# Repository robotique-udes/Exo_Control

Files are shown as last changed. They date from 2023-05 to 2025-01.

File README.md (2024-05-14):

# Exo_Control

## Table of Contents

- [Exo\_Control](#exo_control)
  - [Table of Contents](#table-of-contents)
  - [Description](#description)
  - [Hardware](#hardware)
  - [Getting Started](#getting-started)
  - [Class description](#class-description)
  - [Testing](#testing)
  - [License](#license)
  - [Acknowledgments](#acknowledgments)
  - [Authors](#authors)

## Description

**BioGénius** is a technical project within the Robotique UdeS group that focuses on designing a lightweight and powerful exoskeleton system. This innovative system provides support to the legs, hips, and back, making walking and load handling easier. Notably, our prototype led the team to secure the first-place position at the Applied Collegiate Exoskeleton (ACE) Competition in the United States in both 2022 and 2023.

Founded in the fall of 2019 by two bioengineering enthusiasts, BioGénius has grown into a team of over fifteen members, bringing together expertise from various engineering disciplines and cohorts. This project represents a pioneering endeavor at the undergraduate engineering level in Quebec.

## Hardware

Our system comprises the following key hardware components:

- **Touch Screen (HMI)**: NX3224F024_11
- **Microcontroller**: ESP32
- **Inertial Measurement Units**: BNO085
- **Motor Drives**: DBH-15
- **Motor**: Servocity 638326

## Getting Started

Getting started with our project is a straightforward process. Simply clone the repository.

## Class description

- main: 
  - Not a class but some things are good to keep in mind:
  - The main is separated in 3 blocs: test, logic and printing
    - Test blocs need to be filled with unit tests for every component, will be commented when not in the process of testing 
    - Logic bloc controls normal operation for the exo, needs to be active when using
    - Printing bloc is for debugging, keep commented otherwise
  - Setup starts IMUs and their wifi functions, comment either of those lines if not needed when testing
- motorControl:
  - This class orchestrates most of the operation in the exo and use the info it receive from various sensors to calculate the needed current for the motors
  - Most of the class is either mathematics or fetching info from other classes
  - Most other classes are called by this one
- imu:
  - BNO055 logic class, used to fetch information from our IMUs, converting it to angles, and sending it to motorControl
  - We use mainly the adafruit bno055 library here
- multiplex:
  - multiplexer control class composed of simple functions used to switch multiplexer chanels
- bnoMultiplex:
  - Bridge between the imu and multiplex classes
  - Used to associate any IMUs to an ID from it's constructor and switch multiplexer channel automatically when using IMU's basic functions
- sonar:
  - Sonar logic class, used to read distance from ground and determine whether or not the foot of the user is grounded
- relay:
  - Relay logic class,  used to turn ON/OFF any relay
- touchScreen:
  - Used to customise the interface and functions of the HMI
- test:
  - Testing class composed of units test for every component
  
## Testing

To ensure the robustness of our system, you can run unit tests on all components by using the Test class.

## License

This project is open source, and you can access the full text of the license [here](link-to-license).

## Acknowledgments

We invite you to explore the [Robotique UdeS website](https://robotiqueudes.ca/) to learn more about our team and discover other intriguing projects we're involved in.

## Authors

The masterminds behind the Exo_Control project are:

- Édouard Moffet, robot 67
- Dannick Bilodeau,  info 68
- Simon Trudeau,  info 68
- Jorand Gagnon,  elec 69

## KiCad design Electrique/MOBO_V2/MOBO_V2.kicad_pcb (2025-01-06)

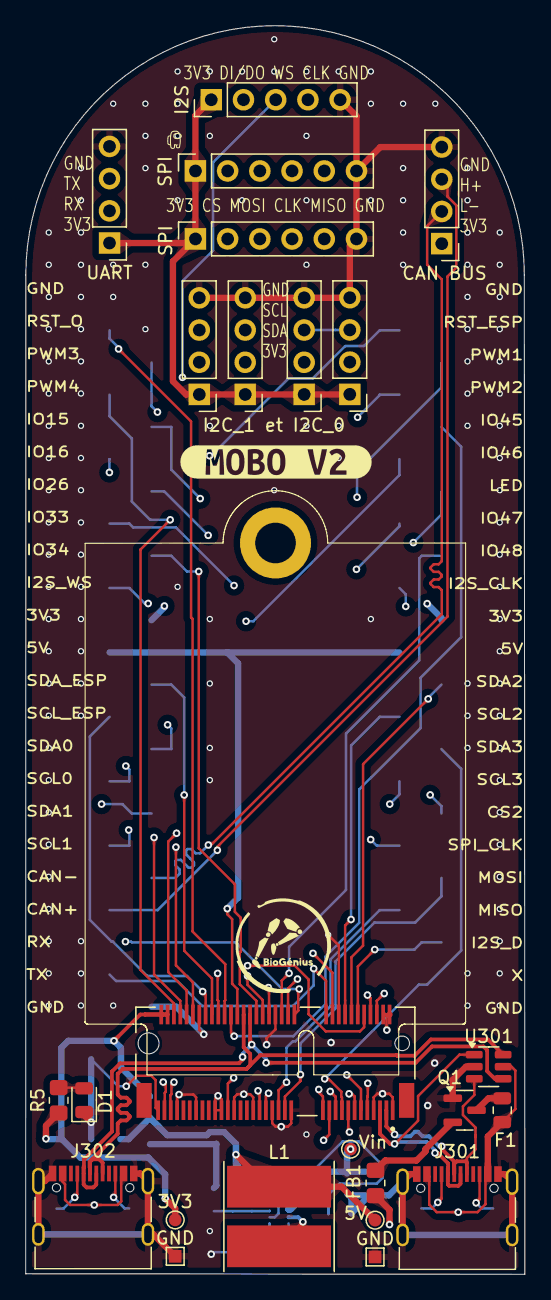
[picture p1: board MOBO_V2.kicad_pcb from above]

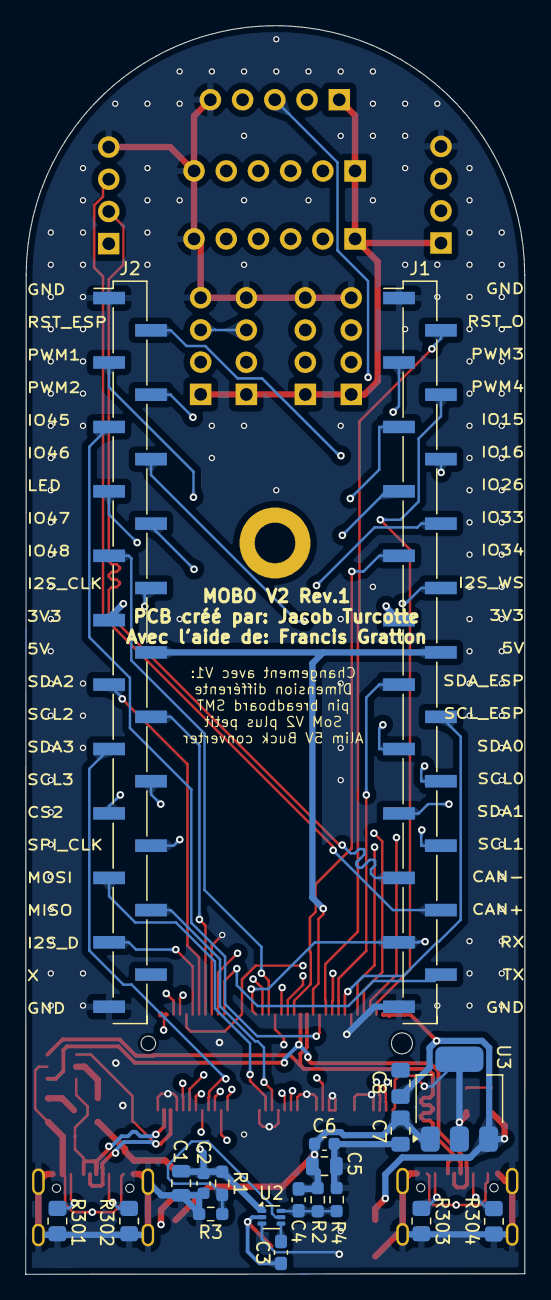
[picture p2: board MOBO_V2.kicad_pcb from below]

Board: 4 copper layers, 39.4 x 98.5 mm, 45 parts (20 on the bottom side), 58 nets.

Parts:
3V3: TP_3v3; TestPoint_Pad_D1.0mm
5V: TP_5V; TestPoint_Pad_D1.0mm
C1: 10µF; C_0805_2012Metric
C2, C6: 0,1µF; C_0603_1608Metric
C3: 0,1µF; C_0603_1608Metric_Pad1.08x0.95mm_HandSolder
C4: 33pF; C_0603_1608Metric_Pad1.08x0.95mm_HandSolder
C5: 22µF; C_0805_2012Metric
C7, C8: 4,7µF; C_0805_2012Metric_Pad1.18x1.45mm_HandSolder
CAN BUS: CAN_BUS; PinHeader_1x04_P2.54mm_Vertical
D1: Green_power; D_0805_2012Metric
F1: SMD0805B110TF; Fuse_0805_2012Metric
FB1: 600 @ 100MHz; R_0805_2012Metric_Pad1.20x1.40mm_HandSolder
GND: TP_GND; TestPoint_Pad_1.0x1.0mm
GND#2: TP_GND_IN; TestPoint_Pad_1.0x1.0mm
I2S: I2S; PinHeader_1x05_P2.54mm_Vertical
J1: Gauche; PinHeader_1x23_P2.54mm_Vertical_SMD_Pin1Left
J2: Droite; PinHeader_1x23_P2.54mm_Vertical_SMD_Pin1Left
J301: USB_C_UART; USB_C_Receptacle_G-Switch_GT-USB-7010ASV
J302: USB_C_DEBUG; USB_C_Receptacle_G-Switch_GT-USB-7010ASV
J307: I2C_0_0; PinHeader_1x04_P2.54mm_Vertical
J308: I2C_0_1; PinHeader_1x04_P2.54mm_Vertical
J309: I2C_1_0; PinHeader_1x04_P2.54mm_Vertical
J310: I2C_1_1; PinHeader_1x04_P2.54mm_Vertical
L1: 3,3µH 20mOhm; L_TDK_VLP8040
Q1: AO3401A; SOT-23
R1: 100k; R_0603_1608Metric_Pad0.98x0.95mm_HandSolder
R2: 158k; R_0603_1608Metric_Pad0.98x0.95mm_HandSolder
R3: 28k; R_0603_1608Metric_Pad0.98x0.95mm_HandSolder
R4: 30k; R_0603_1608Metric_Pad0.98x0.95mm_HandSolder
R5: 330; R_0805_2012Metric_Pad1.20x1.40mm_HandSolder
R301, R302, R303, R304: 5.1k; R_0805_2012Metric_Pad1.20x1.40mm_HandSolder
SPI: Conn_SPI; PinSocket_1x06_P2.54mm_Vertical
SPI#2: Conn_Module_SD; PinSocket_1x06_P2.54mm_Vertical
U1: AMPHENOL_MDT320E01001
U2: TPS562242DRLR; SOT-563
U3: AP7361C-33E; SOT-223-3_TabPin2
U301: SRV05-4; SOT-23-6
UART: UART; PinHeader_1x04_P2.54mm_Vertical
Vin: TP_VIN; TestPoint_Pad_D1.0mm
kibuzzard-66E82988: G***; kibuzzard-66E82988

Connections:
CAN_N: CAN BUS.2, J1.19, U1.73 (CAN_L_MCP2515)
CAN_P: CAN BUS.3, J1.20, U1.71 (CAN_H_MCP2515)
CHIP_EN: J2.2, U1.56 (RESET_ESP32)
CS_1: SPI#2.2, U1.20 (CS_1)
CS_2: J2.17, SPI.2, U1.21 (CS_2)
DEBUG_D+: J302.A6 (D+), J302.B6 (D+), U1.48 (USB_DEBUG_D+), U301.6 (IO4)
DEBUG_D-: J302.A7 (D-), J302.B7 (D-), U1.46 (USB_DEBUG_D-), U301.4 (IO3)
FT231_D+: J301.A6 (D+), J301.B6 (D+), U1.3 (USB_D+_FT231), U301.3 (IO2)
FT231_D-: J301.A7 (D-), J301.B7 (D-), U1.5 (USB_D-_FT231), U301.1 (IO1)
GND: C1.2, C2.2, C5.2, C6.2, C7.1, C8.1, CAN BUS.4, D1.1 (K), GND.1, GND#2.1, I2S.5, J1.1, J1.23, J2.1, J2.23, J301.A1 (GND), J301.A12 (GND), J301.B1 (GND), J301.B12 (GND), J301.S1 (SHIELD), J302.A1 (GND), J302.A12 (GND), J302.B1 (GND), J302.B12 (GND), J302.S1 (SHIELD), J307.4, J308.4, J309.4, J310.4, Q1.1 (G), R3.2, R4.2, R301.2, R302.2, R303.2, R304.2, SPI.6, SPI#2.6, U1.1 (GND), U1.7 (GND), U1.18 (GND), U1.33 (GND), U1.38 (GND), U1.39 (GND), U1.45 (GND), U1.51 (GND), U1.55 (GND), U1.57 (GND), U1.62 (GND), U1.63 (GND), U1.69 (GND), U1.75 (GND), U2.3 (GND), U3.2 (GND), U301.2 (VN), UART.4
GPIO15: J1.5, U1.40 (GPIO15)
GPIO16: J1.6, U1.41 (GPIO16)
GPIO17_U1_TXD: J1.22, U1.22 (UART_TX), UART.3
GPIO18_U1_RXD: J1.21, U1.32 (UART_RX), UART.2
GPIO26: J1.7, U1.42 (GPIO26)
GPIO33: J1.8, U1.43 (GPIO33)
GPIO34: J1.9, U1.44 (GPIO34)
GPIO38_ADDRESSABLE_LED: J2.7, U1.6 (GPIO38&LED)
GPIO45: J2.5, U1.52 (GPIO45)
GPIO46: J2.6, U1.53 (GPIO46)
GPIO47: J2.8, U1.34 (RST_OTHER)
GPIO48/CAN_INT: J2.9, U1.36 (GPIO48)
I2C_SCL_0_TCA: J1.16, J307.3, J308.3, U1.11 (I2C_SCL_1_TCA)
I2C_SCL_1_TCA: J1.18, J309.3, J310.3, U1.15 (I2C_SCL_2_TCA)
I2C_SCL_2_TCA: J2.14, U1.16 (I2C_SCL_3_TCA)
I2C_SCL_3_TCA: J2.16, U1.19 (I2C_SCL_4_TCA)
I2C_SCL_ESP32: J1.14, U1.60 (I2C_SCL_ESP32)
I2C_SDA_0_TCA: J1.15, J307.2, J308.2, U1.9 (I2C_SDA_1_TCA)
I2C_SDA_1_TCA: J1.17, J309.2, J310.2, U1.13 (I2C_SDA_2_TCA)
I2C_SDA_2_TCA: J2.13, U1.14 (I2C_SDA_3_TCA)
I2C_SDA_3_TCA: J2.15, U1.17 (I2C_SDA_4_TCA)
I2C_SDA_ESP32: J1.13, U1.58 (I2C_SDA_ESP32)
I2S_BCLK: I2S.4, J2.10, U1.8 (I2S_BCLK)
I2S_DIN/DOUT: I2S.2, J2.21, U1.12 (I2S_DIN/DOUT)
I2S_WS: I2S.3, J1.10, U1.10 (I2S_WS)
unnamed: D1.2 (A), R5.2
unnamed: J301.A5 (CC1), R302.1
unnamed: J301.B5 (CC2), R301.1
unnamed: J302.A5 (CC1), R304.1
unnamed: J302.B5 (CC2), R303.1
unnamed: F1.2, Q1.3 (D)
unnamed: FB1.1, Q1.2 (S)
unnamed: R1.2, R3.1, U2.5 (EN)
unnamed: C3.1, L1.1, U2.2 (SW)
unnamed: C3.2, U2.4 (VBST)
unnamed: C4.2, R2.2, R4.1, U2.6 (VFB)
PWM_1: J2.3, U1.64 (PWM_1_PCA)
PWM_2: J2.4, U1.66 (PWM_2_PCA)
PWM_3: J1.3, U1.68 (PWM_3_PCA)
PWM_4: J1.4, U1.70 (PWM_4_PCA)
RESET_OTHERS: J1.2, U1.54 (RESET_AUTRES)
SPI_CLK_ESP32: J2.18, SPI.4, SPI#2.4, U1.23 (SPI_CLK)
SPI_MISO_ESP32: J2.20, SPI.5, SPI#2.5, U1.37 (SPI_MISO)
SPI_MOSI_ESP32: J2.19, SPI.3, SPI#2.3, U1.35 (SPI_MOSI)
VBUS: F1.1, J301.A4 (VBUS), J301.A9 (VBUS), J301.B4 (VBUS), J301.B9 (VBUS), J302.A4 (VBUS), J302.A9 (VBUS), J302.B4 (VBUS), J302.B9 (VBUS), U301.5 (VP)
VIN_PROTECTION: C1.1, C2.1, FB1.2, R1.1, U2.1 (VIN), Vin.1
Vcc_3V3: 3V3.1, C8.2, CAN BUS.1, I2S.1, J1.11, J2.11, J307.1, J308.1, J309.1, J310.1, R5.1, SPI.1, SPI#2.1, U1.2 (Vcc_3v3), U1.4 (Vcc_3v3), U1.72 (Vcc_3v3), U1.74 (Vcc_3v3), U3.3 (VO), UART.1
Vcc_5V: 5V.1, C4.1, C5.1, C6.1, C7.2, J1.12, J2.12, L1.2, R2.1, U1.50 (Vcc_5V), U3.1 (VI)

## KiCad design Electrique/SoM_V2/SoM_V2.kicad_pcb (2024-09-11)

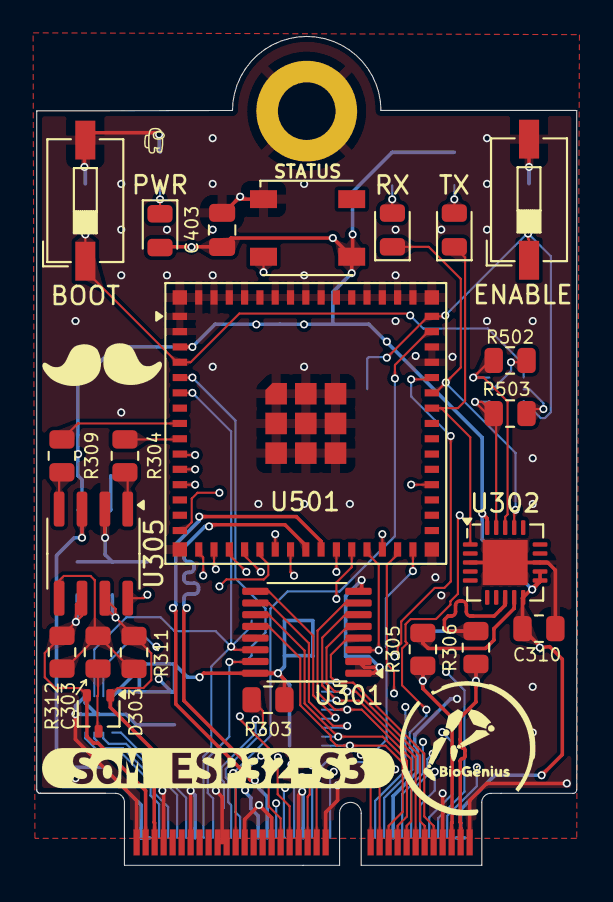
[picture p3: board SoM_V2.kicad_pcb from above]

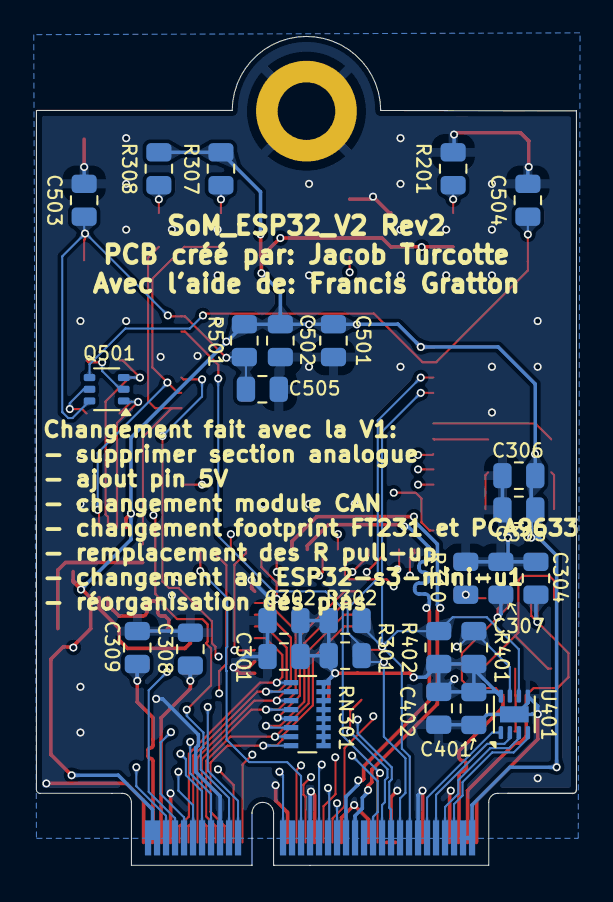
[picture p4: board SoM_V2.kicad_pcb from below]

Board: 4 copper layers, 30.0 x 46.1 mm, 52 parts (27 on the bottom side), 62 nets.

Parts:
BOOT: SW_BOOT; SW_DIP_SPSTx01_Slide_6.7x4.1mm_W6.73mm_P2.54mm_LowProfile_J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
C301, C501: 10µF; R_0805_2012Metric
C302, C304, C306, C307, C310, C502, C504, C505: 0.1µF; R_0805_2012Metric
C303, C305, C401, C503: 1µF; R_0805_2012Metric
C308, C309: 47pF; R_0805_2012Metric
C402: 100nF; R_0805_2012Metric
C403: 100n; C_0805_2012Metric
D303: SP0502BAJT; SOT-323_SC-70
ENABLE: SW_CHIP_EN; SW_DIP_SPSTx01_Slide_6.7x4.1mm_W6.73mm_P2.54mm_LowProfile_J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
PWR: GREEN; LED_0805_2012Metric
Q501: MBT3904DW1T1G; SOT-363_SC-70-6
R201, R307, R308: 330; R_0805_2012Metric
R301, R302, R303, R304, R309, R310, R401, R402: 1k; R_0805_2012Metric
R305, R306: 27; R_0805_2012Metric
R311, R312: 60; R_0805_2012Metric
R501, R502, R503: 10k; R_0805_2012Metric
RN301: R_Pack08_Split; R_Array_Convex_8x0602
RX: TX; LED_0805_2012Metric
STATUS: FZ2812-5050; LED_Inolux_IN-PI554FCH_PLCC4_5.0x5.0mm_P3.2mm
TX: RX; LED_0805_2012Metric
U201: NGFF_E
U301: TCA9546APWR; TSSOP-16_4.4x5mm_P0.65mm
U302: FT231XQ; QFN-20-1EP_4x4mm_P0.5mm_EP2.5x2.5mm
U305: SN65HVD230; SOIC-8_3.9x4.9mm_P1.27mm
U401: PCA9633DP1; DFN-8-1EP_2x2mm_P0.5mm_EP0.9x1.6mm
U501: ESP32-S3-MINI-1U; ESP32-S2-MINI-1U
kibuzzard-66E094ED: G***; kibuzzard-66E094ED

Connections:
/Communication/CAN+: C307.2, D303.1 (K), R311.1, U201.71 (CAN_H_MCP2515), U305.7 (CANH)
/Communication/CAN-: C304.1, D303.2 (K), R312.2, U201.73 (CAN_L_MCP2515), U305.6 (CANL)
/Communication/D+: R306.2, U302.8 (USBDP)
/Communication/D-: R305.2, U302.9 (USBDM)
/Communication/DR+: C309.1, R306.1, U201.3 (USB_D+_FT231)
/Communication/DR-: C308.1, R305.1, U201.5 (USB_D-_FT231)
CHIP_EN: C503.1, C505.1, ENABLE.1, Q501.6 (C1), R501.2, U201.56 (RESET_ESP32), U501.45 (EN)
CS_1: U201.20 (CS_1), U501.15 (IO11)
CS_2: U201.21 (CS_2), U501.25 (IO21)
DEBUG+: U201.48 (USB_DEBUG_D+), U501.24 (IO20)
DEBUG-: U201.46 (USB_DEBUG_D-), U501.23 (IO19)
DTR: Q501.3 (C2), R502.1, U302.18 (~DTR)
GND: BOOT.2, C301.2, C302.2, C304.2, C305.2, C306.2, C307.1, C308.2, C309.2, C310.2, C401.2, C402.2, C403.2, C501.2, C502.2, C503.2, C504.2, C505.2, ENABLE.2, R201.2, R310.1, STATUS.1 (VSS), U201.1 (GND), U201.7 (GND), U201.18 (GND), U201.33 (GND), U201.38 (GND), U201.39 (GND), U201.45 (GND), U201.51 (GND), U201.55 (GND), U201.57 (GND), U201.62 (GND), U201.63 (GND), U201.69 (GND), U201.75 (GND), U301.1 (A0), U301.2 (A1), U301.8 (GND), U301.13 (A2), U302.3 (GND), U302.13 (GND), U302.21 (GND), U305.2 (GND), U401.5 (GND), U501.1 (GND), U501.2 (GND), U501.42 (GND), U501.43 (GND), U501.46 (GND), U501.47 (GND), U501.48 (GND), U501.49 (GND), U501.50 (GND), U501.51 (GND), U501.52 (GND), U501.53 (GND), U501.54 (GND), U501.55 (GND), U501.56 (GND), U501.57 (GND), U501.58 (GND), U501.59 (GND), U501.60 (GND), U501.61 (GND), U501.62 (GND), U501.63 (GND), U501.64 (GND), U501.65 (GND)
GPIO0_BOOT: BOOT.1, C504.1, Q501.4 (E2), U501.4 (IO0)
GPIO4/RXD: R309.1, U501.8 (IO4)
GPIO5/TXD: R304.1, U501.9 (IO5)
GPIO15: U201.40 (GPIO15), U501.19 (IO15)
GPIO16: U201.41 (GPIO16), U501.20 (IO16)
GPIO17_U1_TXD: U201.22 (UART_TX), U501.21 (IO17)
GPIO18_U1_RXD: U201.32 (UART_RX), U501.22 (IO18)
GPIO26: U201.42 (GPIO26), U501.26 (IO26)
GPIO33: U201.43 (GPIO33), U501.28 (IO33)
GPIO34: U201.44 (GPIO34), U501.29 (IO34)
GPIO38_ADDRESSABLE_LED: STATUS.2 (DIN), U201.6 (GPIO38&LED), U501.34 (IO38)
GPIO45: U201.52 (GPIO45), U501.41 (IO45)
GPIO46: U201.53 (GPIO46), U501.44 (IO46)
GPIO48/CAN_INT: U201.36 (GPIO48), U501.30 (IO48)
I2C_SCL_0_TCA: RN301.2 (R2.1), U201.11 (I2C_SCL_1_TCA), U301.5 (SC0)
I2C_SCL_1_TCA: RN301.4 (R4.1), U201.15 (I2C_SCL_2_TCA), U301.7 (SC1)
I2C_SCL_2_TCA: RN301.6 (R6.1), U201.16 (I2C_SCL_3_TCA), U301.10 (SC2)
I2C_SCL_3_TCA: RN301.8 (R8.1), U201.19 (I2C_SCL_4_TCA), U301.12 (SC3)
I2C_SCL_ESP32: R302.2, R402.2, U201.60 (I2C_SCL_ESP32), U301.14 (SCL), U401.6 (SCL6), U501.6 (IO2)
I2C_SDA_0_TCA: RN301.1 (R1.1), U201.9 (I2C_SDA_1_TCA), U301.4 (SD0)
I2C_SDA_1_TCA: RN301.3 (R3.1), U201.13 (I2C_SDA_2_TCA), U301.6 (SD1)
I2C_SDA_2_TCA: RN301.5 (R5.1), U201.14 (I2C_SDA_3_TCA), U301.9 (SD2)
I2C_SDA_3_TCA: RN301.7 (R7.1), U201.17 (I2C_SDA_4_TCA), U301.11 (SD3)
I2C_SDA_ESP32: R301.2, R401.2, U201.58 (I2C_SDA_ESP32), U301.15 (SDA), U401.7 (SDA), U501.5 (IO1)
I2S_BCLK: U201.8 (I2S_BCLK), U501.16 (IO12)
I2S_DIN/DOUT: U201.12 (I2S_DIN/DOUT), U501.18 (IO14)
I2S_WS: U201.10 (I2S_WS), U501.17 (IO13)
unnamed: PWR.2 (A), R201.1
unnamed: R307.1, RX.2 (A)
unnamed: R308.1, TX.2 (A)
unnamed: C303.2, D303.3 (A)
unnamed: Q501.2 (B1), R502.2
unnamed: Q501.5 (B2), R503.2
unnamed: U201.64 (PWM_1_PCA), U401.1 (PWM1)
unnamed: U201.66 (PWM_2_PCA), U401.2 (PWM2)
unnamed: U201.68 (PWM_3_PCA), U401.3 (PWM3)
unnamed: U201.70 (PWM_4_PCA), U401.4 (PWM4)
unnamed: R304.2, U305.1 (D)
unnamed: R309.2, U305.4 (R)
unnamed: R310.2, U305.8 (Rs)
RESET_OTHERS: R303.2, U201.54 (RESET_AUTRES), U301.3 (RESET_N), U501.27 (IO47)
RTS: Q501.1 (E1), R503.1, U302.19 (~RTS)
SPI_CLK_ESP32: U201.23 (SPI_CLK), U501.10 (IO6)
SPI_MISO_ESP32: U201.37 (SPI_MISO), U501.12 (IO8)
SPI_MOSI_ESP32: U201.35 (SPI_MOSI), U501.11 (IO7)
U0RXD: RX.1 (K), U302.17 (TXD), U501.40 (RXD0)
U0TXD: TX.1 (K), U302.1 (RXD), U501.39 (TXD0)
Vcc_3V3: C301.1, C302.1, C305.1, C306.1, C310.1, C401.1, C402.1, C403.1, C501.1, C502.1, PWR.1 (K), R301.1, R302.1, R303.1, R307.2, R308.2, R401.1, R402.1, R501.1, RN301.9 (R8.2), RN301.10 (R7.2), RN301.11 (R6.2), RN301.12 (R5.2), RN301.13 (R4.2), RN301.14 (R3.2), RN301.15 (R2.2), RN301.16 (R1.2), STATUS.3 (VDD), U201.2 (Vcc_3v3), U201.4 (Vcc_3v3), U201.72 (Vcc_3v3), U201.74 (Vcc_3v3), U301.16 (VCC), U302.10 (3V3OUT), U302.11 (~RESET), U302.12 (VCC), U302.20 (VCCIO), U305.3 (VCC), U401.8 (VCC), U501.3 (3V3)
Vref_CAN: C303.1, R311.2, R312.1, U305.5 (Vref)

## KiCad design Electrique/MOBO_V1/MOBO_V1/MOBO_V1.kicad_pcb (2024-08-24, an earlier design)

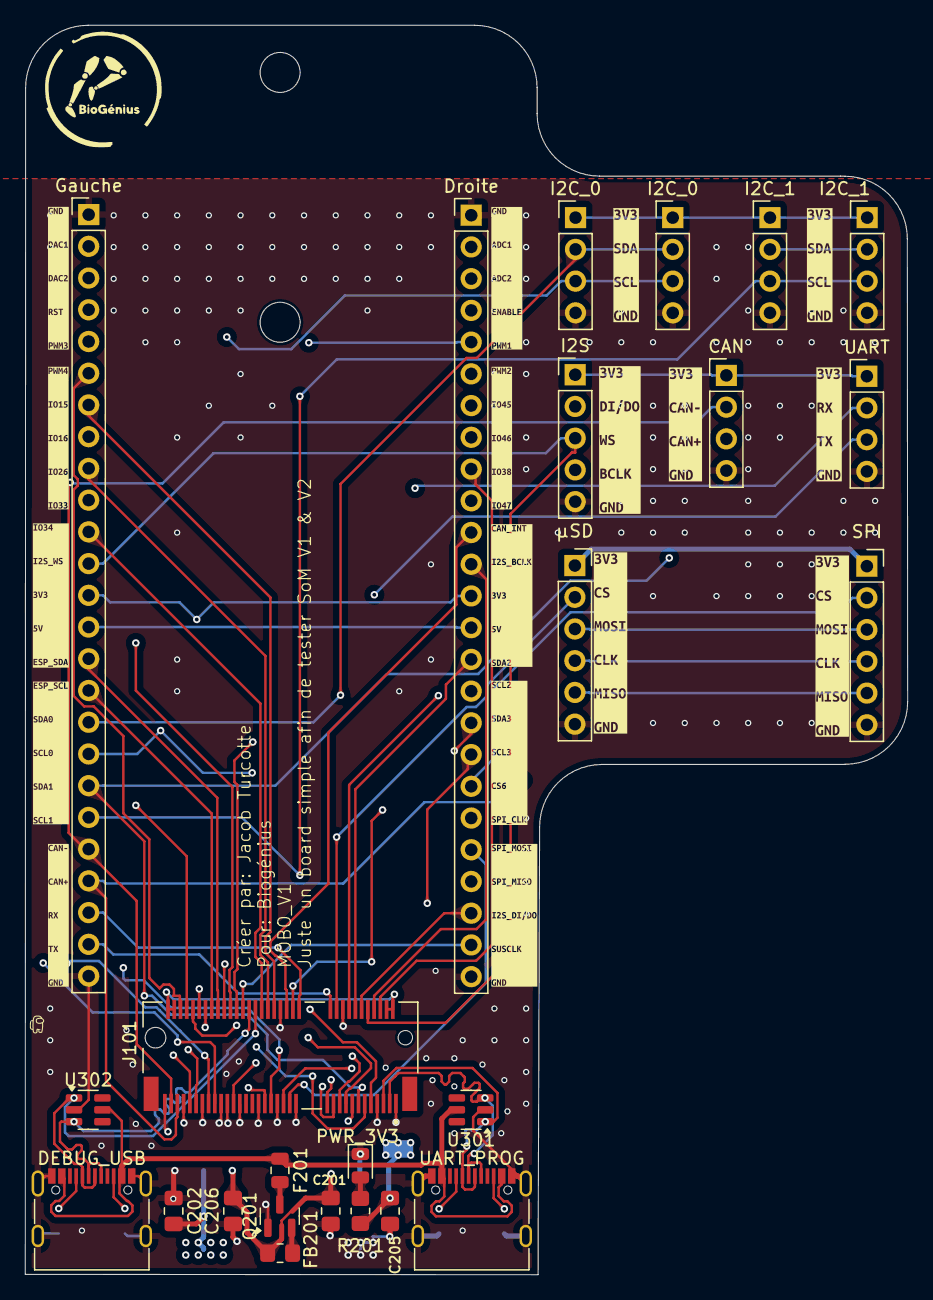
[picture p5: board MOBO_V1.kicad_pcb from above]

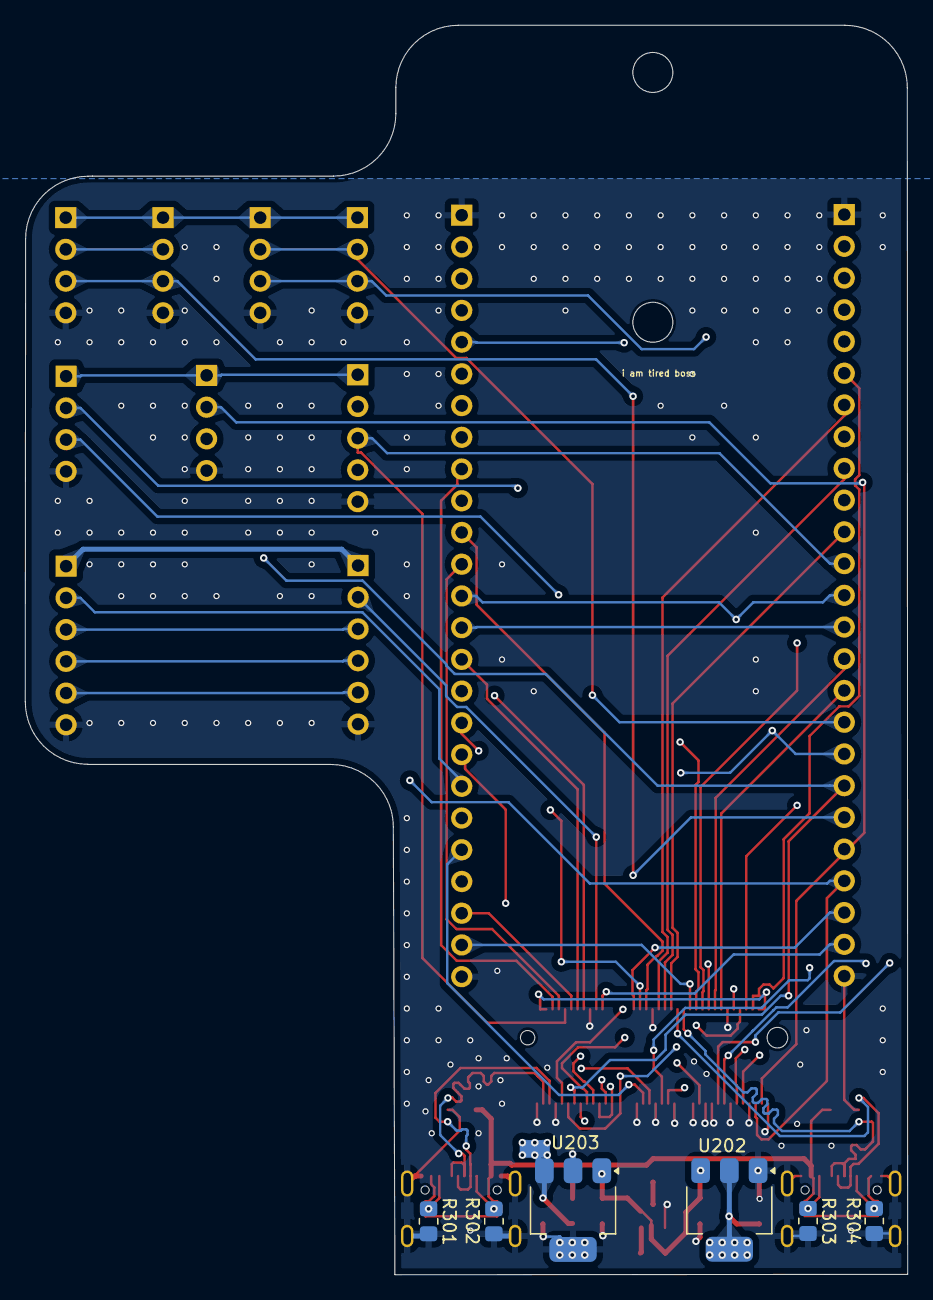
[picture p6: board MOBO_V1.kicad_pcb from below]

Board: 4 copper layers, 70.6 x 100.0 mm, 50 parts (6 on the bottom side), 60 nets.

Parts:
C201: 10uF; C_0805_2012Metric_Pad1.18x1.45mm_HandSolder
C202: 22µF; C_0805_2012Metric_Pad1.18x1.45mm_HandSolder
C205, C206: 4,7µF; C_0805_2012Metric_Pad1.18x1.45mm_HandSolder
CAN: CAN_BUS; PinHeader_1x04_P2.54mm_Vertical
DEBUG_USB: USB_C_DEBUG; USB_C_Receptacle_G-Switch_GT-USB-7010ASV
Droite: Droite; PinHeader_1x25_P2.54mm_Vertical
F201: SMD0805B110TF; Fuse_0805_2012Metric
FB201: 600 @ 100MHz; R_0805_2012Metric_Pad1.20x1.40mm_HandSolder
Gauche: Gauche; PinHeader_1x25_P2.54mm_Vertical
I2C_0: I2C_0_1; PinHeader_1x04_P2.54mm_Vertical
I2C_0#2: I2C_0_0; PinHeader_1x04_P2.54mm_Vertical
I2C_1: I2C_1_0; PinHeader_1x04_P2.54mm_Vertical
I2C_1#2: I2C_1_1; PinHeader_1x04_P2.54mm_Vertical
I2S: I2S; PinHeader_1x05_P2.54mm_Vertical
J101: AMPHENOL_MDT320E01001
PWR_3V3: Green_power; D_0805_2012Metric
Q201: AO3401A; SOT-23
R201: 330; R_0805_2012Metric_Pad1.20x1.40mm_HandSolder
R301, R302, R303, R304: 5.1k; R_0805_2012Metric_Pad1.20x1.40mm_HandSolder
SPI: Conn_SPI; PinSocket_1x06_P2.54mm_Vertical
U202: AMS1117-5.0; SOT-223-3_TabPin2
U203: AP7361C-33E; SOT-223-3_TabPin2
U301, U302: SRV05-4; SOT-23-6
UART: UART; PinHeader_1x04_P2.54mm_Vertical
UART_PROG: USB_C_UART; USB_C_Receptacle_G-Switch_GT-USB-7010ASV
V1_mount, V2_mount: MountingHole_3.2mm_M3
kibuzzard-66C7DEE4, kibuzzard-66C7DEE4#2: G***; kibuzzard-66C7DEE4
kibuzzard-66C7DFF5: G***; kibuzzard-66C7DFF5
kibuzzard-66C7E0B6, kibuzzard-66C7E0B6#2: G***; kibuzzard-66C7E0B6
kibuzzard-66C7E03B: G***; kibuzzard-66C7E03B
kibuzzard-66C7E5D1: G***; kibuzzard-66C7E5D1
kibuzzard-66C7E5F8: G***; kibuzzard-66C7E5F8
kibuzzard-66C7E7D8: G***; kibuzzard-66C7E7D8
kibuzzard-66C7E69C: G***; kibuzzard-66C7E69C
kibuzzard-66C7E73E: G***; kibuzzard-66C7E73E
kibuzzard-66C7E79D: G***; kibuzzard-66C7E79D
kibuzzard-66C7E81E: G***; kibuzzard-66C7E81E
kibuzzard-66C7E082: G***; kibuzzard-66C7E082
kibuzzard-66C7E82F: G***; kibuzzard-66C7E82F
kibuzzard-66C7E605: G***; kibuzzard-66C7E605
kibuzzard-66C7E879: G***; kibuzzard-66C7E879
µSD: Conn_Module_SD; PinSocket_1x06_P2.54mm_Vertical

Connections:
+3.3V: SPI.1, µSD.1
ADC_1: Droite.2, J101.65 (ADC_1_MCP3202)
ADC_2: Droite.3, J101.67 (ADC_2_MCP3202)
CAN_H: CAN.3, Gauche.22, J101.71 (CAN_H_MCP2515)
CAN_L: CAN.2, Gauche.21, J101.73 (CAN_L_MCP2515)
CHIP_EN: Droite.4, J101.56 (RESET_ESP32)
DAC_1: Gauche.2, J101.59 (DAC_1_MCP48)
DAC_2: Gauche.3, J101.61 (DAC_2_MCP48)
DEBUG_D+: DEBUG_USB.A6 (D+), DEBUG_USB.B6 (D+), J101.48 (USB_DEBUG_D+), U302.3 (IO2)
DEBUG_D-: DEBUG_USB.A7 (D-), DEBUG_USB.B7 (D-), J101.46 (USB_DEBUG_D-), U302.1 (IO1)
FT231_D+: J101.3 (USB_D+_FT231), U301.3 (IO2), UART_PROG.A6 (D+), UART_PROG.B6 (D+)
FT231_D-: J101.5 (USB_D-_FT231), U301.1 (IO1), UART_PROG.A7 (D-), UART_PROG.B7 (D-)
GND: C201.1, C202.1, C205.1, C206.1, CAN.4, DEBUG_USB.A1 (GND), DEBUG_USB.A12 (GND), DEBUG_USB.B1 (GND), DEBUG_USB.B12 (GND), DEBUG_USB.S1 (SHIELD), Droite.1, Droite.25, Gauche.1, Gauche.25, I2C_0.4, I2C_0#2.4, I2C_1.4, I2C_1#2.4, I2S.5, J101.1 (GND), J101.7 (GND), J101.18 (GND), J101.33 (GND), J101.38 (GND), J101.39 (GND), J101.45 (GND), J101.51 (GND), J101.55 (GND), J101.57 (GND), J101.62 (GND), J101.63 (GND), J101.69 (GND), J101.75 (GND), PWR_3V3.1 (K), Q201.1 (G), R301.2, R302.2, R303.2, R304.2, SPI.6, U202.1 (GND), U203.2 (GND), U301.2 (VN), U302.2 (VN), UART.4, UART_PROG.A1 (GND), UART_PROG.A12 (GND), UART_PROG.B1 (GND), UART_PROG.B12 (GND), UART_PROG.S1 (SHIELD), µSD.6
GPIO15: Gauche.7, J101.40 (GPIO15)
GPIO16: Gauche.8, J101.41 (GPIO16)
GPIO17_U1_TXD: Gauche.24, J101.22 (UART_TX), UART.3
GPIO18_U1_RXD: Gauche.23, J101.32 (UART_RX), UART.2
GPIO26: Gauche.9, J101.42 (GPIO26)
GPIO33: Gauche.10, J101.43 (GPIO33)
GPIO34: Gauche.11, J101.44 (GPIO34)
GPIO38_ADDRESSABLE_LED: Droite.9, J101.6 (GPIO38&LED)
GPIO45: Droite.7, J101.52 (GPIO45)
GPIO46: Droite.8, J101.53 (GPIO46)
GPIO47: Droite.10, J101.34 (GPIO47)
GPIO48/CAN_INT: Droite.11, J101.36 (GPIO48)
I2C_SCL_0_TCA: Gauche.18, I2C_0.3, I2C_0#2.3, J101.11 (I2C_SCL_1_TCA)
I2C_SCL_1_TCA: Gauche.20, I2C_1.3, I2C_1#2.3, J101.15 (I2C_SCL_2_TCA)
I2C_SCL_2_TCA: Droite.16, J101.16 (I2C_SCL_3_TCA)
I2C_SCL_3_TCA: Droite.18, J101.19 (I2C_SCL_4_TCA)
I2C_SCL_ESP32: Gauche.16, J101.60 (I2C_SCL_ESP32)
I2C_SDA_0_TCA: Gauche.17, I2C_0.2, I2C_0#2.2, J101.9 (I2C_SDA_1_TCA)
I2C_SDA_1_TCA: Gauche.19, I2C_1.2, I2C_1#2.2, J101.13 (I2C_SDA_2_TCA)
I2C_SDA_2_TCA: Droite.15, J101.14 (I2C_SDA_3_TCA)
I2C_SDA_3_TCA: Droite.17, J101.17 (I2C_SDA_4_TCA)
I2C_SDA_ESP32: Gauche.15, J101.58 (I2C_SDA_ESP32)
I2S_BCLK: Droite.12, I2S.4, J101.8 (I2S_BCLK)
I2S_DIN/DOUT: Droite.23, I2S.2, J101.12 (I2S_DIN/DOUT)
I2S_WS: Gauche.12, I2S.3, J101.10 (I2S_WS)
unnamed: PWR_3V3.2 (A), R201.2
unnamed: R302.1, UART_PROG.A5 (CC1)
unnamed: R301.1, UART_PROG.B5 (CC2)
unnamed: DEBUG_USB.A5 (CC1), R304.1
unnamed: DEBUG_USB.B5 (CC2), R303.1
unnamed: F201.2, Q201.3 (D)
unnamed: FB201.1, Q201.2 (S)
PWM_1: Droite.5, J101.64 (PWM_1_PCA)
PWM_2: Droite.6, J101.66 (PWM_2_PCA)
PWM_3: Gauche.5, J101.68 (PWM_3_PCA)
PWM_4: Gauche.6, J101.70 (PWM_4_PCA)
RESET_OTHERS: Gauche.4, J101.54 (RESET_AUTRES)
SPI_5_ESP32: J101.20 (SPI_CS_5), µSD.2
SPI_6_ESP32: Droite.19, J101.21 (SPI_CS_6), SPI.2
SPI_CLK_ESP32: Droite.20, J101.23 (SPI_CLK), SPI.4, µSD.4
SPI_MISO_ESP32: Droite.22, J101.37 (SPI_MISO), SPI.5, µSD.5
SPI_MOSI_ESP32: Droite.21, J101.35 (SPI_MOSI), SPI.3, µSD.3
SUSCLK: Droite.24, J101.50 (SUSCLK)
VBUS: DEBUG_USB.A4 (VBUS), DEBUG_USB.A9 (VBUS), DEBUG_USB.B4 (VBUS), DEBUG_USB.B9 (VBUS), F201.1, U301.5 (VP), U302.5 (VP), UART_PROG.A4 (VBUS), UART_PROG.A9 (VBUS), UART_PROG.B4 (VBUS), UART_PROG.B9 (VBUS)
VIN_PROTECTION: C201.2, C206.2, FB201.2, U202.3 (VI), U203.1 (VI)
Vcc_3V3: C205.2, CAN.1, Droite.13, Gauche.13, I2C_0.1, I2C_0#2.1, I2C_1.1, I2C_1#2.1, I2S.1, J101.2 (Vcc_3v3), J101.4 (Vcc_3v3), J101.72 (Vcc_3v3), J101.74 (Vcc_3v3), R201.1, U203.3 (VO), UART.1
Vcc_5V: C202.2, Droite.14, Gauche.14, U202.2 (VO)

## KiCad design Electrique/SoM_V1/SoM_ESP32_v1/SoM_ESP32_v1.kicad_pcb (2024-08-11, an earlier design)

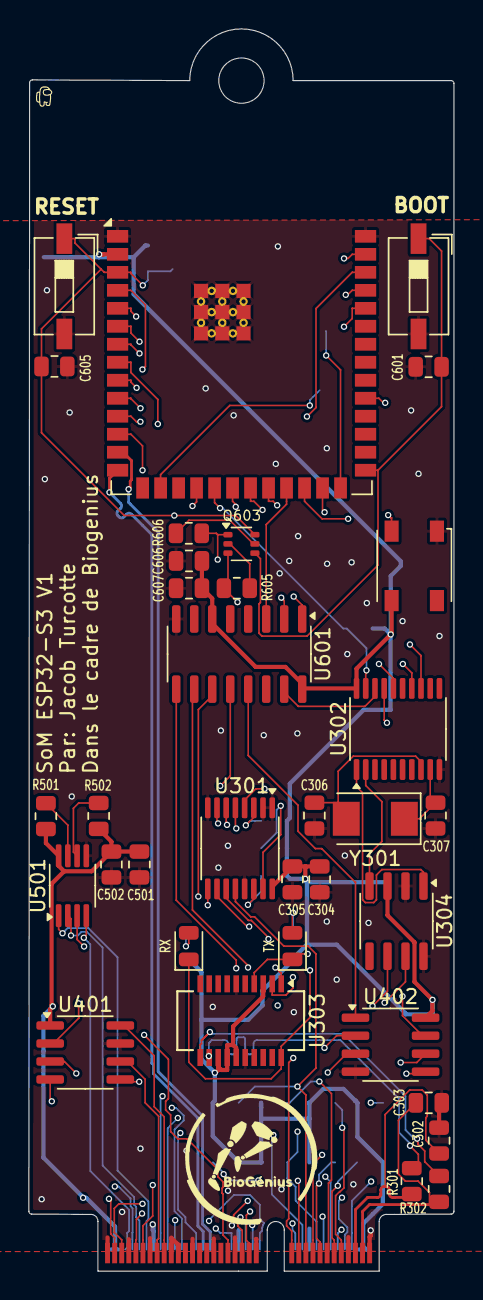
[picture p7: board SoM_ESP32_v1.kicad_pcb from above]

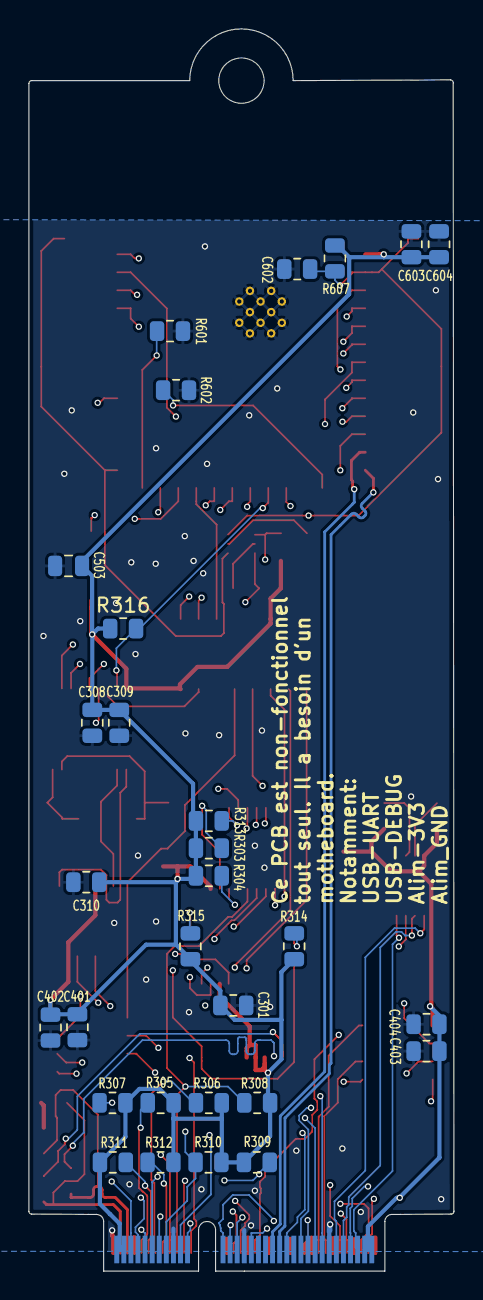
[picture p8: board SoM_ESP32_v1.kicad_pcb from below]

Board: 4 copper layers, 30.0 x 87.7 mm, 64 parts (29 on the bottom side), 70 nets.

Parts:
C301, C305, C309, C310, C402, C404, C601, C604, C605, C607: 0.1µF; R_0805_2012Metric
C302, C303: 47pF; R_0805_2012Metric
C304, C308, C401, C403, C603: 10µF; R_0805_2012Metric
C306, C307: 22pF; R_0805_2012Metric
C501, C602, C606: 1µF; R_0805_2012Metric
C502: 100nF; R_0805_2012Metric
C503: 100n; C_0805_2012Metric
D501: FZ2812-5050; LED_Inolux_IN-PI554FCH_PLCC4_5.0x5.0mm_P3.2mm
J201: NGFF_E
Q603: MBT3904DW1T1G; SOT-363_SC-70-6
R301, R302: 27; R_0805_2012Metric
R303, R304, R305, R306, R307, R308, R309, R310, R311, R312, R313: 1k; R_0805_2012Metric
R314, R315: 330; R_0805_2012Metric
R316, R501, R502, R601, R602, R605, R606, R607: 10k; R_0805_2012Metric
RX: TX; LED_0805_2012Metric
SW601: SW_BOOT; SW_DIP_SPSTx01_Slide_6.7x4.1mm_W6.73mm_P2.54mm_LowProfile_J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
SW602: SW_CHIP_EN; SW_DIP_SPSTx01_Slide_6.7x4.1mm_W6.73mm_P2.54mm_LowProfile_J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
TX: RX; LED_0805_2012Metric
U301: TCA9546APWR; TSSOP-16_4.4x5mm_P0.65mm
U302: MCP2515-xST; TSSOP-20_4.4x6.5mm_P0.65mm
U303: FT231XS; SSOP-20_3.9x8.7mm_P0.635mm
U304: TJA1051T; SOIC-8_3.9x4.9mm_P1.27mm
U401: MCP4822; SOIC-8_3.9x4.9mm_P1.27mm
U402: MCP3202; SOIC-8_3.9x4.9mm_P1.27mm
U501: PCA9633DP1; MSOP-8_3x3mm_P0.65mm
U601: 74HC238; SOIC-16_3.9x9.9mm_P1.27mm
U701: ESP32-S3-WROOM-2
Y301: 8MHz; Crystal_SMD_Abracon_ABM3-2Pin_5.0x3.2mm

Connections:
/Communication/D+: R302.2, U303.11 (USBDP)
/Communication/D-: R301.2, U303.12 (USBDM)
/Communication/DR+: C303.1, J201.3 (USB_D+_FT231), R302.1
/Communication/DR-: C302.1, J201.5 (USB_D-_FT231), R301.1
CHIP_EN: C602.1, C605.1, J201.56 (RESET_ESP32), Q603.6 (C1), R607.2, SW602.1, U701.3 (EN)
DEBUG+: J201.48 (USB_DEBUG_D+), U701.14 (USB_D+/IO20)
DEBUG-: J201.46 (USB_DEBUG_D-), U701.13 (USB_D-/IO19)
DTR: Q603.3 (C2), R605.1, U303.1 (~DTR)
ESP32_SCL: R502.2, U501.6 (SCL)
ESP32_SDA: R501.2, U501.7 (SDA)
GND: C301.2, C302.2, C303.2, C304.2, C305.2, C306.2, C307.2, C308.2, C309.2, C310.2, C401.2, C402.2, C403.1, C404.1, C501.2, C502.2, C503.2, C601.2, C602.2, C603.2, C604.2, C605.2, C606.2, C607.2, D501.1 (VSS), J201.1 (GND), J201.7 (GND), J201.18 (GND), J201.33 (GND), J201.38 (GND), J201.39 (GND), J201.45 (GND), J201.51 (GND), J201.55 (GND), J201.57 (GND), J201.62 (GND), J201.63 (GND), J201.69 (GND), J201.75 (GND), R601.2, R602.2, SW601.2, SW602.2, U301.1 (A0), U301.2 (A1), U301.8 (GND), U301.13 (A2), U302.10 (VSS), U303.6 (GND), U303.16 (GND), U304.2 (GND), U304.8 (S), U401.7 (Vss), U402.4 (VSS), U501.5 (GND), U601.8 (GND), U701.1 (GND), U701.40 (GND), U701.41 (GND)
GPIO0_BOOT: C601.1, Q603.4 (E2), SW601.1, U701.27 (IO0)
GPIO15: J201.40 (GPIO15), U701.8 (IO15)
GPIO16: J201.41 (GPIO16), U701.9 (IO16)
GPIO17_U1_TXD: J201.22 (UART_TX), U701.10 (IO17)
GPIO18_U1_RXD: J201.32 (UART_RX), U701.11 (IO18)
GPIO38_ADDRESSABLE_LED: D501.2 (DIN), J201.6 (GPIO38&LED), U701.31 (IO38)
GPIO47: J201.34 (GPIO47), U701.24 (IO47)
GPIO48/CAN_INT: J201.36 (GPIO48), U302.13 (~INT), U701.25 (IO48)
I2C_SCL_0_TCA: J201.11 (I2C_SCL_1_TCA), R311.2, U301.5 (SC0)
I2C_SCL_1_TCA: J201.15 (I2C_SCL_2_TCA), R312.2, U301.7 (SC1)
I2C_SCL_2_TCA: J201.16 (I2C_SCL_3_TCA), R310.2, U301.10 (SC2)
I2C_SCL_3_TCA: J201.19 (I2C_SCL_4_TCA), R308.2, U301.12 (SC3)
I2C_SCL_ESP32: J201.60 (I2C_SCL_ESP32), R304.2, U301.14 (SCL), U701.38 (IO2)
I2C_SDA_0_TCA: J201.9 (I2C_SDA_1_TCA), R305.2, U301.4 (SD0)
I2C_SDA_1_TCA: J201.13 (I2C_SDA_2_TCA), R306.2, U301.6 (SD1)
I2C_SDA_2_TCA: J201.14 (I2C_SDA_3_TCA), R309.2, U301.9 (SD2)
I2C_SDA_3_TCA: J201.17 (I2C_SDA_4_TCA), R307.2, U301.11 (SD3)
I2C_SDA_ESP32: J201.58 (I2C_SDA_ESP32), R303.2, U301.15 (SDA), U701.39 (IO1)
I2S_BCLK: J201.8 (I2S_BCLK), U701.20 (IO12)
I2S_DIN/DOUT: J201.12 (I2S_DIN/DOUT), U701.22 (IO14)
I2S_WS: J201.10 (I2S_WS), U701.21 (IO13)
LDAC_DAC: U401.5 (~LDAC), U601.11 (Y4)
unnamed: R314.1, RX.2 (A)
unnamed: R315.1, TX.2 (A)
unnamed: J201.71 (CAN_H_MCP2515), U304.7 (CANH)
unnamed: J201.73 (CAN_L_MCP2515), U304.6 (CANL)
unnamed: J201.65 (ADC_1_MCP3202), U402.2 (CH0)
unnamed: J201.67 (ADC_2_MCP3202), U402.3 (CH1)
unnamed: J201.59 (DAC_1_MCP48), U401.8 (VA)
unnamed: J201.61 (DAC_2_MCP48), U401.6 (VB)
unnamed: J201.64 (PWM_1_PCA), U501.1 (PWM1)
unnamed: J201.66 (PWM_2_PCA), U501.2 (PWM2)
unnamed: J201.68 (PWM_3_PCA), U501.3 (PWM3)
unnamed: J201.70 (PWM_4_PCA), U501.4 (PWM4)
unnamed: Q603.2 (B1), R605.2
unnamed: Q603.5 (B2), R606.2
unnamed: C307.1, U302.9 (OSC1), Y301.1
unnamed: C306.1, U302.8 (OSC2), Y301.2
unnamed: U302.2 (RXCAN), U304.4 (RXD)
unnamed: U302.1 (TXCAN), U304.1 (TXD)
unnamed: U601.1 (A0), U701.4 (IO4)
unnamed: U601.2 (A1), U701.5 (IO5)
unnamed: U601.3 (A2), U701.23 (IO21)
unnamed: R601.1, U701.26 (IO45)
unnamed: R602.1, U701.16 (IO46)
RESET_OTHERS: J201.54 (RESET_AUTRES), R313.2, R316.2, U301.3 (RESET_N), U302.19 (~RESET), U701.19 (IO11)
RTS: Q603.1 (E1), R606.1, U303.2 (~RTS)
SPI_5_ESP32: J201.20 (SPI_CS_1), U601.10 (Y5)
SPI_6_ESP32: J201.21 (SPI_CS_2), U601.9 (Y6)
SPI_ADC_ESP32: U402.1 (~CS/SHDN), U601.13 (Y2)
SPI_CAN_ESP32: U302.18 (~CS), U601.15 (Y0)
SPI_CLK_ESP32: J201.23 (SPI_CLK), U302.14 (SCK), U401.3 (SCK), U402.7 (CLK), U701.6 (IO6)
SPI_DAC_ESP32: U401.2 (~CS), U601.12 (Y3)
SPI_MISO_ESP32: J201.37 (SPI_MISO), U302.17 (SO), U402.6 (DOUT), U701.12 (IO8)
SPI_MOSI_ESP32: J201.35 (SPI_MOSI), U302.16 (SI), U401.4 (SDI), U402.5 (DIN), U701.7 (IO7)
SUSCLK: J201.50 (SUSCLK), U701.18 (IO10)
U0RXD: RX.1 (K), U303.20 (TXD), U701.36 (RXD0/IO44)
U0TXD: TX.1 (K), U303.4 (RXD), U701.37 (TXD0/IO43)
Vcc_3V3: C301.1, C304.1, C305.1, C308.1, C309.1, C310.1, C401.1, C402.1, C403.2, C404.2, C501.1, C502.1, C503.1, C603.1, C604.1, C606.1, C607.1, D501.3 (VDD), J201.2 (Vcc_3v3), J201.4 (Vcc_3v3), J201.72 (Vcc_3v3), J201.74 (Vcc_3v3), R303.1, R304.1, R305.1, R306.1, R307.1, R308.1, R309.1, R310.1, R311.1, R312.1, R313.1, R314.2, R315.2, R316.1, R501.1, R502.1, R607.1, U301.16 (VCC), U302.20 (VDD), U303.3 (VCCIO), U303.13 (3V3OUT), U303.14 (~RESET), U303.15 (VCC), U304.3 (VCC), U401.1 (Vdd), U402.8 (VDD/VREF), U501.8 (VCC), U601.6 (E3), U601.16 (VCC), U701.2 (3V3)

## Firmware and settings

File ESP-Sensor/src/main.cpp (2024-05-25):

#include <Arduino.h>
#include <HardwareSerial.h>
#include "enumIMU.h"
#include "PinExtender.h"
#include "QuadratureEncoder.h"
#include "biogeniusImu.h"
#include "touchScreen.h"
#include <SPI.h>
#include <SD.h>
#include <Nextion.h>
#include <string.h>
#include "motorControl.h"
#include "test.h"
#include "touchScreen.h"
#include "callbackSetup.h"
#include "exoSettings.h"
#include "enumAngleSource.h"

Test tester;
Relay relais;
Motor *motor;
// Handler must be a pointer because Wire needs to be instanciated
IMU *imuHandler;
QuadratureEncoder encoder;
TouchScreen &screen = TouchScreen::getInstance();
ExoSettings &settings = ExoSettings::getInstance();

void updateAngles(bool angleSource);

//===============================================================================================================
//===================================================(SETUP)=====================================================
//===============================================================================================================

void setup()
{
  Serial.begin(115200);
  nexInit();

  Serial2.begin(9600, SERIAL_8N1, 16, 17);

  // IMU setup
  Wire.setPins(MAIN_I2C_SDA, MAIN_I2C_SCL);
  Wire.begin();

  // Setup devices using I2C
  imuHandler = new IMU();
  motor = new Motor();

  pinExtender.begin();
  QuadratureEncoder::begin();
  tester.setMotor(motor);
  tester.setEncoder(&encoder);
  pwmPinExtender.resetDevices();
  pwmPinExtender.init();
  settings.init(&encoder);

  motor->setPins();
  relais.setPins();

  relais.setAllRelais(OFF);

  // Setup HMI
  setupCallbacks();
  // imu01.IMUSetup(); // Comment if no IMU are in use
  // imu01.wifiSetup(); // Comment if not using wifi com
}

void loop()
{

  //--------------Test BLOC----------------

  // motor->motorSetSpeed(MOTEUR_GENOU_GAUCHE, 4000);
  // motor->motorSetSpeed(MOTEUR_GENOU_DROIT, 4000);
  // motor->motorSetSpeed(MOTEUR_HANCHE_GAUCHE, 4000);
  // motor->motorSetSpeed(MOTEUR_HANCHE_DROITE, 4000);
  //tester.testRelay();
  // tester.keyboardCommand();

  //--------------LOGIC BLOC---------------
  screen.update();
  updateAngles(settings.getAngleSource());
  // motor->sonarRead(); //Ne pas décommenter, remplace par HMI
  motor->neededTorque();
  
  // motor->neededCurrent(); Ne pas décommenter, pas utile sans PID
  // motor->readCurrent(); Ne pas décommenter, pas utile sans PID
  motor->PIDCurrentPrealable();
  motor->sendCommand();

  //--------------PRINTING BLOC-------------
  // Serial.print(motor->getPower());
  // imuHandler->printBNOs(0, 4);
  // motor->printProxim();
  // motor->printPMW();
  // motor->printTorque();
  //delay(200);

  
}

void updateAngles(bool angleSource)
{
  if(angleSource){
    //Fetch angles from IMUs
    imuHandler->requestData();
    motor->setAngle(enumIMU::HIP_R, imuHandler->getValAngle(enumIMU::HIP_R));
    motor->setAngle(enumIMU::HIP_L, imuHandler->getValAngle(enumIMU::HIP_L));
    motor->setAngle(enumIMU::KNEE_R, imuHandler->getValAngle(enumIMU::KNEE_R));
    motor->setAngle(enumIMU::KNEE_L, imuHandler->getValAngle(enumIMU::KNEE_L));
  }
  else{
    //Fetch angles from ENCODERs
    motor->setAngle(enumIMU::HIP_R, encoder.getPositionAngle(QuadratureEncoder::HAN_DRO));
    motor->setAngle(enumIMU::HIP_L, encoder.getPositionAngle(QuadratureEncoder::HAN_GAU));
    motor->setAngle(enumIMU::KNEE_R, encoder.getPositionAngle(QuadratureEncoder::GEN_DRO));
    motor->setAngle(enumIMU::KNEE_L, encoder.getPositionAngle(QuadratureEncoder::GEN_GAU));
  }
}

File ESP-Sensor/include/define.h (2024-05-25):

// PINS SONAR

//**********PAS LES BONNES PINS************
#define SDA_PIN_GAUCHE 15
#define SCL_PIN_GAUCHE 39
#define SDA_PIN_DROIT 23
#define SCL_PIN_DROIT 35
//constant SONAR
#define UNCERTAINTY 0.1
#define LOW 0x0
#define HIGH 0x1

// ------------ MOTOR -------------
#define K_RESSORT 0.25
#define DIST_CM 0.245
#define MASSE 0.366
#define PULSE_PAR_TOUR 300
#define TORQUE2CURRENT 0.6 // 6.470
#define KP 2.5
#define KI 0
#define KD 0
#define HIGH_TORQUE 100
#define PI 3.141592653

#define MOTEUR_GENOU_GAUCHE 0
#define MOTEUR_GENOU_DROIT 1
#define MOTEUR_HANCHE_GAUCHE 2
#define MOTEUR_HANCHE_DROITE 3

#define PIN_MD_HAN_DRO_INB 0 // Pin INB pour le moteur de la hanche droite
#define PIN_MD_HAN_DRO_INA 1 // Pin INA pour le moteur de la hanche droite
#define PIN_MD_HAN_GAU_INB 2 // Pin INB pour le moteur de la hanche gauche
#define PIN_MD_HAN_GAU_INA 3 // Pin INA pour le moteur de la hanche gauche
#define PIN_MD_GEN_DRO_INB 4 // Pin INB pour le moteur du genou droit
#define PIN_MD_GEN_DRO_INA 5 // Pin INA pour le moteur du genou droit
#define PIN_MD_GEN_GAU_INB 6 // Pin INB pour le moteur du genou gauche
#define PIN_MD_GEN_GAU_INA 7 // Pin INA pour le moteur du genou gauche

#define PIN_MD_GEN_GAU_EN 0  // Pin EN pour le moteur du genou gauche
#define PIN_MD_GEN_DRO_EN 3  // Pin EN pour le moteur du genou droit
#define PIN_MD_HAN_GAU_EN 7 // Pin EN pour le moteur de la hanche gauche
#define PIN_MD_HAN_DRO_EN 10 // Pin EN pour le moteur de la hanche droite

#define PIN_MD_HAN_GAU_CT 36 // Pin de current sensing pour le moteur de la hanche gauche
#define PIN_MD_HAN_DRO_CT 39 // Pin de current sensing pour le moteur de la hanche droite
#define PIN_MD_GEN_GAU_CT 34 // Pin de current sensing pour le moteur du genou gauche
#define PIN_MD_GEN_DRO_CT 35 // Pin de current sensing pour le moteur du genou droit

// LONGUEURS
#define LH 0.5  // longueur haut du corps
#define LF 0.4  // longueur femur
#define LT 0.4  // longueur tibia
#define G 9.81  // gravité
#define MH 25.0 // Masse haut du corps/2
#define MF 3.0  // Masse femur
#define MT 3.0  // Masse tibia

#define ClockWise 1
#define CounterClockWise -1

#define MOTEUR_GENOU_GAUCHE 0
#define MOTEUR_GENOU_DROIT 1
#define MOTEUR_HANCHE_GAUCHE 2
#define MOTEUR_HANCHE_DROITE 3
#define SONAR_GAUCHE 0
#define SONAR_DROIT 1

#define RELAIS_GENOU_GAUCHE 13
#define RELAIS_GENOU_DROIT 14
#define RELAIS_HANCHE_GAUCHE 15
#define RELAIS_HANCHE_DROITE 16

#define ON 1
#define OFF 0

//------ I2C --------
#define I2C_SDA1 26
#define I2C_SCL1 27
#define I2C_SDA2 33
#define I2C_SCL2 32
#define I2C_SDA3 25
#define I2C_SCL3 14

#define IMU_DEBUG true
#define MAIN_I2C_SDA 21
#define MAIN_I2C_SCL 22
#define LEFT_MOUSTACHE_MUX_CHANNEL 1
#define RIGHT_MOUSTACHE_MUX_CHANNEL 2 
#define I2C_CLOCK   400000L 

//------ PROXIM ------
#define PROXIM_REFRESH_RATE 4
#define BUFFER_SIZE 6     
#define GROUND_DISTANCE_RANGE 40


/* Set the delay between fresh samples */
#define BNO055_SAMPLERATE_DELAY_MS (800)

//------ TOUCH SCREEN ------
#define RX_HMI 16
#define TX_HMI 17

//------ SETTINGS -------
#define WALK_MODE 0
#define SQUAT_MODE 1
#define FROM_IMU 1
#define FROM_ENCODER 0
#define MOTOR_INCREASE 5

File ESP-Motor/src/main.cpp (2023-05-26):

#include <Arduino.h>
#include <HardwareSerial.h>
#include <string>
#include "motorControl.h"



HardwareSerial SerialPort(1);

char bitOfMessage = ' ';
std::string message = " ";

int MGGin1Val = 0;
int MGGin2Val = 0;
int MGGpwmMotor = 0;
int MGDin1Val = 0;
int MGDin2Val = 0;
int MGDpwmMotor = 0;
int MHGin1Val = 0;
int MHGin2Val = 0;
int MHGpwmMotor = 0;
int MHDin1Val = 0;
int MHDin2Val = 0;
int MHDpwmMotor = 0;

Motor motor;



void setup()
{
  Serial.begin(9600);
  SerialPort.begin(9600, SERIAL_8N1, 18, 19);
  pinMode(D1_IN1_A, OUTPUT);
  pinMode(D1_IN2_A, OUTPUT);
  pinMode(D1_EN_A, OUTPUT);
  pinMode(D2_IN1_A, OUTPUT);
  pinMode(D2_IN1_A, OUTPUT);
  pinMode(D2_IN1_A, OUTPUT);
  pinMode(D1_IN1_B, OUTPUT);
  pinMode(D1_IN2_B, OUTPUT);
  pinMode(D1_EN_B, OUTPUT);
  pinMode(D2_IN1_B, OUTPUT);
  pinMode(D2_IN1_B, OUTPUT);
  pinMode(D2_IN1_B, OUTPUT);
  







  Serial.println("setup done");

}



void loop()
{
  if (SerialPort.available())
  {
    bitOfMessage = char(SerialPort.read());
    if (bitOfMessage != '\n'){
      message += bitOfMessage;
    }
    else{
      MGGin1Val = std::stoi(message.substr(2,1));
      MGGin2Val = std::stoi(message.substr(3,1));;
      MGGpwmMotor = std::stoi(message.substr(4,3));
      MGDin1Val = std::stoi(message.substr(8,1));;
      MGDin2Val = std::stoi(message.substr(9,1));;
      MGDpwmMotor = std::stoi(message.substr(10,3));
      MHGin1Val = std::stoi(message.substr(14,1));;
      MHGin2Val = std::stoi(message.substr(15,1));;
      MHGpwmMotor = std::stoi(message.substr(16,3));
      MHDin1Val = std::stoi(message.substr(20,1));;
      MHDin2Val = std::stoi(message.substr(21,1));;
      MHDpwmMotor = std::stoi(message.substr(22,3));

      motor.motorSetSpeed(MOTEUR_GENOU_GAUCHE, MGGin1Val, MGGin2Val, MGGpwmMotor);
      motor.motorSetSpeed(MOTEUR_GENOU_DROIT, MGDin1Val, MGDin2Val, MGDpwmMotor);
      motor.motorSetSpeed(MOTEUR_HANCHE_GAUCHE, MHGin1Val, MHGin2Val, MHGpwmMotor);
      motor.motorSetSpeed(MOTEUR_HANCHE_DROITE, MHDin1Val, MHDin2Val, MHDpwmMotor);

      Serial.print(MGGin1Val);
      Serial.print(MGGin2Val);
      Serial.print(MGGpwmMotor);
      Serial.print("   ");
      Serial.print(MGDin1Val);
      Serial.print(MGDin2Val);
      Serial.print(MGDpwmMotor);
      Serial.print("   ");
      Serial.print(MHGin1Val);
      Serial.print(MHGin2Val);
      Serial.print(MHGpwmMotor);
      Serial.print("   ");
      Serial.print(MHDin1Val);
      Serial.print(MHDin2Val);
      Serial.println(MHDpwmMotor);

      message = " ";
    
    }
  }
}

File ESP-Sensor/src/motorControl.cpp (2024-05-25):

#include "motorControl.h"

Motor::Motor()
{
  this->mux = Multiplex();
  this->LeftProxim = new ProxiSensor(&this->mux, LEFT_MOUSTACHE_MUX_CHANNEL);
  this->RightProxim = new ProxiSensor(&this->mux, RIGHT_MOUSTACHE_MUX_CHANNEL);
}

Motor::~Motor()
{
}

void Motor::setPins()
{
  pinMode(PIN_MD_HAN_GAU_CT, INPUT);
  pinMode(PIN_MD_HAN_DRO_CT, INPUT);
  pinMode(PIN_MD_GEN_GAU_CT, INPUT);
  pinMode(PIN_MD_GEN_DRO_CT, INPUT);

  pinExtender.pinMode(PIN_MD_GEN_GAU_EN, OUTPUT);
  pinExtender.pinMode(PIN_MD_GEN_DRO_EN, OUTPUT);
  pinExtender.pinMode(PIN_MD_HAN_GAU_EN, OUTPUT);
  pinExtender.pinMode(PIN_MD_HAN_DRO_EN, OUTPUT);
}
void Motor::readCurrent()
{
  RightKneeMeasuredCurrent = ((analogRead(PIN_MD_GEN_DRO_CT) * 27.0) / 1023.0) * 1000.0;
  LeftKneeMeasuredCurrent = ((analogRead(PIN_MD_GEN_GAU_CT) * 27.0) / 1023.0) * 1000.0;
  RightHipMeasuredCurrent = ((analogRead(PIN_MD_HAN_DRO_CT) * 27.0) / 1023.0) * 1000.0;
  LeftHipMeasuredCurrent = ((analogRead(PIN_MD_HAN_GAU_CT) * 27.0) / 1023.0) * 1000.0;
}

void Motor::LimitMinMaxFloat(float &val, float max)
{
  if (val > max)
    val = max;
  else if (val < -max)
    val = -max;
}

void Motor::LimitMinMaxInt(int &val, int max)
{
  if (val > max)
    val = max;
  else if (val < -max)
    val = -max;
}

void Motor::neededTorque()
{
  bool rightIsOnGround;
  bool leftIsOnGround;
  //Fetch squat/walk logic from either proxim or HMI
  if(settings.isProximEnabled()){
    rightIsOnGround = !RightProxim->IsOnTheGround();
    leftIsOnGround = !RightProxim->IsOnTheGround();
  }
  else{
    rightIsOnGround = settings.getproximState();
    leftIsOnGround = settings.getproximState();
  }
  float LeftHipRAD = toRadian(LeftHipAngle);
  float LeftKneeRAD = toRadian(LeftKneeAngle);
  float RightHipRAD = toRadian(RightHipAngle);
  float RightKneeRAD = toRadian(RightKneeAngle);
  //check if proxim to reset trigger dist
  if(settings.getResetProxim())
  {
    SetTriggerDistance();
    settings.setResetProxim(false);
  }
  // If clutch are on automatic, calculate torque needed
  if (settings.isMotorEnabled())
  {
    // Right Hip Torque Equation
    if (!rightIsOnGround)
      RightHipTorque = (MF * G) * sin(RightHipRAD) * LF / 2 + (MT * G) * (sin(RightHipRAD) * LF + sin(RightKneeRAD - RightHipRAD) * LT / 2); // TODO : TEST THIS NEW EQUATION
    else
    {
      if (RightHipAngle < 110)
      {
        RightHipTorque = -(sin(RightHipRAD) * (LF / 2.0) * (MF * G)) * 8;
      }
      else
        RightHipTorque = 0;
    }

    // Left Hip Torque Equation
    if (!leftIsOnGround)
      LeftHipTorque = (MF * G) * sin(LeftHipRAD) * LF / 2 + (MT * G) * (sin(LeftHipRAD) * LF + sin(LeftKneeRAD - LeftHipRAD) * LT / 2); // TODO : TEST THIS NEW EQUATION
    else
    {
      if (LeftHipAngle < 110)
        LeftHipTorque = -(sin(LeftHipRAD) * (LF / 2.0) * (MF * G)) * 8;
      else
        LeftHipTorque = 0;
    }

    // Right Knee Torque Equation
    if (!rightIsOnGround)
    {
      if (RightKneeAngle > 0)
        RightKneeTorque = ((sin(RightHipRAD) * (LF / 2) * (MF * G)) + ((sin(RightHipRAD) * LF)) * (G * MH)) * 0.5;
      else
        RightKneeAngle = 0;
    }
    else
    {
      if (RightKneeAngle < 110)
        RightKneeTorque = -(sin(RightKneeRAD - RightHipRAD) * (LT / 2.0) * (MT * G)) * 8; //*4 ajoute pour augmenter force necessaire
      else
        RightKneeTorque = 0;
    }

    // Left Knee Torque Equation
    if (!leftIsOnGround)
    {
      if (LeftKneeAngle > 0)
        LeftKneeTorque = ((sin(LeftHipRAD) * (LF / 2) * (MF * G)) + ((sin(LeftHipRAD) * LF)) * (G * MH)) * 0.5;
      else
        LeftKneeTorque = 0;
    }
    else
    {
      if (LeftKneeAngle < 110)
        LeftKneeTorque = -(sin(LeftKneeRAD - LeftHipRAD) * (LT / 2.0) * (MT * G)) * 8; //*4 ajoute pour augmenter force necessaire
      else
        LeftKneeTorque = 0;
    }
  }
  else
  {
    LeftHipTorque = 0;
    RightHipTorque = 0;
    LeftKneeTorque = 0;
    RightKneeTorque = 0;
  }
}

void Motor::printTorque()
{
  Serial.print("  NeededTorqueHL: \t");
  Serial.print(LeftHipTorque);
  Serial.print("  NeededTorqueRH: \t");
  Serial.print(RightHipTorque);
  Serial.print("  NeededTorqueLK: \t");
  Serial.print(LeftKneeTorque);
  Serial.print("  NeededTorqueRK: \t");
  Serial.println(RightKneeTorque);
}

void Motor::neededCurrent()
{
  RightKneeNeededCurrent = (RightKneeTorque / TORQUE2CURRENT) * 1000;
  LeftKneeNeededCurrent = (LeftKneeTorque / TORQUE2CURRENT) * 1000;
  RightHipNeededCurrent = (RightHipTorque / TORQUE2CURRENT) * 1000;
  LeftHipNeededCurrent = (LeftHipTorque / TORQUE2CURRENT) * 1000;
}

void Motor::PIDCurrent()
{
  // TODO : In the future, use PID control instead of direct PWM control using map in PIDCurrentPrealable
  //        For now, the PID control is not working properly, so we use the map function to set the PWM values

  /*
    // Set error values on measured current compared to needed current determined by torque
    ErrorCurrentRightKnee = RightKneeNeededCurrent - RightKneeMeasuredCurrent;
    ErrorCurrentLeftKnee = LeftKneeNeededCurrent - LeftKneeMeasuredCurrent;

    // Update integral values depending on calculated errors
    IntegralRightKnee += ErrorCurrentRightKnee;
    IntegralLeftKnee += ErrorCurrentLeftKnee;

    // Update derivative values depending on the rate of change of the calculated errors
    DerivativeRightKnee = ErrorCurrentRightKnee - PreviousErrorRightKnee;
    DerivativeLeftKnee = ErrorCurrentLeftKnee - PreviousErrorLeftKnee;

    // Capping the error values
    LimitMinMaxFloat(ErrorCurrentRightKnee, 5);
    LimitMinMaxFloat(ErrorCurrentLeftKnee, 5);

    // LimitMinMaxFloat(derivative, 50);
    // Setting both PWM values
    PWMRightKnee += KP * ErrorCurrentRightKnee + KI * IntegralRightKnee + KD * DerivativeRightKnee;
    PWMLeftKnee += KP * ErrorCurrentLeftKnee + KI * IntegralLeftKnee + KD * DerivativeLeftKnee;

    // Setting the previous errors for both motors
    PreviousErrorRightKnee = ErrorCurrentRightKnee;
    PreviousErrorLeftKnee = ErrorCurrentLeftKnee;

    // Capping the PWM values for both motors
    LimitMinMaxInt(PWMRightKnee, 255);
    LimitMinMaxInt(PWMLeftKnee, 255);

    //if (angle < 0.2 || angle > (2 * PI - 0.2))
      //PWM = 0;

    */
}

void Motor::PIDCurrentPrealable()
{
  int power = settings.getMotorPower();

  // Setting  PWM values
  PWMRightKnee = -float(map(RightKneeTorque, -HIGH_TORQUE, HIGH_TORQUE, -power, power));
  PWMLeftKnee = float(map(LeftKneeTorque, -HIGH_TORQUE, HIGH_TORQUE, -power, power));
  PWMRightHip = float(map(RightHipTorque, -HIGH_TORQUE, HIGH_TORQUE, -power, power));
  PWMLeftHip = -float(map(LeftHipTorque, -HIGH_TORQUE, HIGH_TORQUE, -power, power));
}
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

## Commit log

2023-02-27 Ajout du programme de contrôle des moteurs
2023-02-27 Changement dans lib "motorControl.h"
2023-03-06 Préparation des fichiers
2023-03-08 Corrections Arduino
2023-03-08 on/off motor
2023-03-28 Ajout const et euq torque comment
2023-03-29 Change value for PID
2023-04-18 update esp32
2023-04-18 Ajout des library interne
2023-04-19 ESP32 test
2023-04-19 Add hmi with esp32
2023-04-25 Ajout des classes et lien avec les librairies ESP
2023-04-26 Sonar & Relais fonctionnel
2023-04-27 Ajout IMU
2023-04-27 IMU dans la classe
2023-04-28 Intégration IMU
2023-05-03 Tests IMU
2023-05-07 Corrections IMU
2023-05-09 Avancement de la programmation du controle des moteurs
    Creation ou ajustement des fonctions readCurrent, neededTorque, neededCurrent et sonarRead
2023-05-09 Ajustement de la fonction PIDCurrent
2023-05-10 Transmission des angles entre les IMU et le moteur
2023-05-10 Code compilable : Tests V1 de valeurs de torque
2023-05-14 Update des equations de torque
2023-05-14 Remap des pin et modification des équation de torque
2023-05-16 Séparation print des fonction de logic
2023-05-16 Add communication between ESP32
2023-05-17 Set de la hauteur des sonar
2023-05-17 Added com esp32 motors
2023-05-18 Equation torque dos
2023-05-18 INversion pin Rx Tx
2023-05-18 Ajout condition de securite
2023-05-19 Gossage pour des fix
    [main.cpp, motorControl.cpp, motorControl.h]
2023-07-12 Maintenant utiliser la classe BNOMultiplex
2023-07-19 Intégration avec de BNOMultiplex
2023-11-08 adding distance sensor class
2023-11-15 WIP Working on BNO08x imu
    C'est rough en criss :( -Antoine
2023-11-28 WIP Two I2C buses
2023-12-13 tadaaaaa
    Code pour chercher les adresses des appareils connecté au multi
2023-12-20 added comment of current problem with distance sensor on leg
    [main.cpp]
2024-01-25 Sonar class created
2024-02-03 Printing gyro of a single IMU
2024-02-08 Single 085 prints correct quaternion values
    [main.cpp]
2024-03-20 Distance sensor print something readable
2024-03-28 Remake des classes en lien avec le HMI
2024-03-28 Ajout d'un Singleton sur la classe TouchScreen
2024-04-03 Made some changes to the sensor class
2024-05-02 🔧 WIP : BNO code complete, multiplexer missing
    [biogeniusBno.cpp]
2024-05-04 🗑️ Removed temporary projects
2024-05-04 🗑️ Removed i2c-scanner for implementation in another branch
2024-05-04 Added i2c-scanner from i2c-testing branch
2024-05-07 GPIO Extender implemented, PWM extender in progress
2024-05-09 Prettier scanner for ACE2024 board
2024-05-09 I2C scanner and fix variable names
    [define.h, main.cpp, motorControl.cpp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]
2024-05-09 added pinExtender to relay
2024-05-09 MotorControl with pin extender and cleaner code
2024-05-10 pwm fonctionel
2024-05-12 WIP Fixing compilation erros
    [biogeniusBno.cpp, biogeniusImu.cpp, main.cpp]
2024-05-13 Code compiles, fixing errors
    [biogeniusBno.cpp, biogeniusImu.cpp, imu.cpp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]
2024-05-13 Add encoders. To be tested
2024-05-15 added print and fixed IMU declaration bug
    [biogeniusBno.cpp, biogeniusImu.cpp, main.cpp]
2024-05-15 Integration
    Début de l'intégration du HMI, besoin d'intégrer avec le GPIO extender et de tester ensuite avant de merge
2024-05-16 Fix bugs in motorcontrol. Encoder working in test code, but to be debbuged in class
    [QuadratureEncoder.cpp, define.h, main.cpp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]
2024-05-17 fix de l'incrémentation des encodeurs dans leur classe
    [QuadratureEncoder.cpp, QuadratureEncoder.h, main.cpp]
2024-05-17 Motor and encoder working. Add command serial from computer
2024-05-20 Added prints and changed name
2024-05-21 Add reset encoder function and encoder in tester
    [QuadratureEncoder.cpp, QuadratureEncoder.h, main.cpp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]
2024-05-21 Fix encoder angles
2024-05-22 Début logique toggle IMU/Encoder
2024-05-22 BNOs accessible through IMU
2024-05-22 IMU fully implemented
2024-05-22 Debug angle from encoder to motor class
2024-05-22 Try IMUs
2024-05-22 BNOs print on exo!
2024-05-22 Correct values computed by IMUs
    [biogeniusBno.cpp, biogeniusImu.cpp, main.cpp]
2024-05-23 Integration IMU dos
2024-05-23 Fix minor display issue
    [main.cpp]
2024-05-23 Random fixes on proxims or wtv
    [ProxiSensor.cpp, main.cpp, motorControl.cpp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]
2024-05-23 Fix bug and compil issue
    [biogeniusImu.cpp, exoSettings.cpp, main.cpp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]
2024-05-24 Fix torque equations
2024-05-24 Fix motor direction and uncomment logic in main
    [main.cpp, motorControl.cpp]
2024-05-24 motor power slider thingy
2024-05-24 fix herp derp des proxim
    [ProxiSensor.cpp, define.h, main.cpp]
2024-06-13 Je mets mes développement électrique sur le github
    [SoM_ESP32_v1.kicad_pcb, SoM_ESP32_v1.kicad_sch]
2024-06-19 changement kicad
    [SoM_ESP32_v1.kicad_sch]
2024-07-09 push connecteur
    [Alimentation.kicad_sch, Analogue.kicad_sch, Communication.kicad_sch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]
2024-08-11 push pcb
    [Alimentation.kicad_sch, Analogue.kicad_sch, Communication.kicad_sch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]
2024-08-24 Push de 3 nouveau board/PCB
    [Alimentation.kicad_sch, Analogue.kicad_sch, Communication.kicad_sch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]
2024-09-03 push pour frank
    [Alimentation.kicad_sch, Analogue.kicad_sch, Communication.kicad_sch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]
2024-09-03 whoops KiCad
    [Communication.kicad_sch]
2024-09-03 stinky kicad
    [Alimentation.kicad_sch, Analogue.kicad_sch, Communication.kicad_sch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]
2024-09-07 push fix ???
    [Alimentation.kicad_sch, Communication.kicad_sch, ESP32.kicad_sch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]
2024-09-07 push v2.2
    [Alimentation.kicad_sch, Communication.kicad_sch, ESP32.kicad_sch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]
2024-09-07 push drc clean up, reste le silkscreen à faire
    [ESP32.kicad_sch, SoM_V2.kicad_pcb]
2024-09-10 Clean up schema et PCB
    [Alimentation.kicad_sch, Analogue.kicad_sch, Communication.kicad_sch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]
2024-09-10 Some Details about Schematics
2024-09-11 Some modif of traces
    [SoM_V2.kicad_pcb]
2024-09-12 push mobo v2
    [MOBO_V1.GBL, MOBO_V1.GBO, MOBO_V1.GBS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]
2024-09-13 upload mobo v2 pcb
    [MOBO_V2.kicad_pcb, MOBO_V2.kicad_sch, connexion.kicad_sch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]
2024-09-16 PCB terminé en attente de vérification
    [MOBO_V2.kicad_pcb, MOBO_V2.kicad_sch, connexion.kicad_sch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]
2024-09-18 verified by frank
    [MOBO_V2.kicad_pcb]
2025-01-06 push pull up sur reset et prog
    [MOBO_V2-B_Cu.gbr, MOBO_V2-B_Mask.gbr, MOBO_V2-B_Silks.gbr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]
